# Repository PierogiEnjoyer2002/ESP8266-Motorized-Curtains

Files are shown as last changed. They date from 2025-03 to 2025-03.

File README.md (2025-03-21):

# 🪟 AutoBlinds – ESP8266 Motorized Curtains Controller

## Overview
AutoBlinds is a DIY smart curtains controller built using **ESP8266 (Wemos D1 Mini)** and a stepper motor. This project allows you to control your window curtains via a web interface and physical buttons.

## Features
- **Dual Control Methods**
  - Web interface accessible from any device on your network
  - Physical buttons for manual operation
  
- **Smart Positioning System**
  - Precise position control with memory
  - Configuration mode to set open/close limits
  
- **Reliable & Customizable**
  - Position memory persists through power cycles (EEPROM storage)
  - Simple configuration for adaptation to different window sizes
  - JSON API for integration with home automation systems

## Bill of Materials
Here's a complete list of components needed for this project:

| Quantity | Component | Specifications |
|---|---|---|
| 1 | NEMA17 Stepper Motor | 1.8° step angle, 2.4 kg/cm holding torque |
| 1 | Wemos D1 Mini | ESP8266-based microcontroller |
| 1 | A4988 Stepper Driver | Pololu or compatible |
| 1 | Mini-360 DC-DC Buck Converter | 12V to 5V for Wemos power |
| 1 | 2.1mm Barrel Jack | With terminal block for power input |
| 2 | Push Buttons | Momentary, normally open |
| 1 | Capacitor | 100uF, 25V (for power stabilization) |
| 1 | Power Supply | 12V DC at least 1,5A|
| - | Various Wires | For connections between components |

## How It Works
1. **The system controls a stepper motor** that opens or closes curtains.
2. **Users operate curtains** via web interface or physical buttons.
3. **Position data is saved** to ensure consistent operation over time.

## 3D Printed Components
This project uses several custom 3D printed parts to create a complete curtain control system:

### Electronics Housing
Electronics Housing

A custom-designed enclosure for the electronics that:
- Securely houses the Wemos D1 Mini, A4988 driver, and DC-DC converter
- Features openings for power and button connections

### Curtain String Guide
String Guide

A specially designed bracket that:
- Guides the curtain string through a smooth path
- Reduces friction for smoother operation
- Prevents tangling during operation
- Easily mounts to window frames of various sizes

### NEMA17 Motor Mount
For the motor mount, I used a design by stevetheprinter:
- Original design available on [Thingiverse](https://www.thingiverse.com/stevetheprinter/designs)
- Features secure mounting for NEMA17 stepper motor

*All STL files for the 3D printed components are included in the `/3d_models` directory of this repository.*

## Installation & Setup

### Hardware Assembly
<p float="left">
  Complete Setup
  Controller Box
</p>

### Software Setup
1. Copy code from repository

2. Configure WiFi Settings
Edit the following lines in the code to match your network:
```cpp
const char* ssid = "Your_WiFi_SSID";       
const char* password = "Your_WiFi_Password"; 
```

3. Configure Static IP
Edit the following lines if you want to use a different IP:
```cpp
IPAddress staticIP(192, 168, 0, 101);
IPAddress gateway(192, 168, 0, 1);
IPAddress subnet(255, 255, 255, 0);
```

4. Upload to ESP8266
Upload the code to your Wemos D1 Mini using the Arduino IDE.

## Usage Instructions

### Web Interface
Access the web interface by navigating to the device's IP address (default: 192.168.0.101) in your web browser.

The interface offers:
- Full open/close buttons
- Stop button
- Position slider for precise control
- Current position and status information

### Physical Buttons
- **Normal Mode:**
  - Short press UP button: Fully open blinds
  - Short press DOWN button: Fully close blinds
  - Press both buttons simultaneously for 3 seconds: Enter configuration mode

- **Configuration Mode:**
  - Short press UP button: Move up continuously (stop with any button)
  - Short press DOWN button: Move down continuously (stop with any button)
  - Long press UP button (3+ seconds): Set current position as fully open
  - Long press DOWN button (3+ seconds): Set current position as fully closed
  - Press both buttons simultaneously for 3 seconds: Exit configuration mode and save settings

### API Endpoint
The system provides a JSON API endpoint at `/status` that returns current position, target position, and operational state.

## Project Images
### Complete Setup
Complete Setup

### Controller Box
Controller Box

### Web Interface
Web Interface

## Video Demonstration
Video showing blinds operation

## Challenges and Solutions
- **Motor Torque Requirements:** Selected NEMA17 motor with sufficient torque for smooth operation.
- **Position Memory:** Implemented EEPROM storage to maintain settings through power cycles.
- **User-Friendly Interface:** Created an intuitive web interface for easy control.
- **3D Printed Components:** Designed custom parts to ensure proper mechanical operation and clean installation.

## Future Improvements
- Add MQTT support for smart home integration (Home Assistant, etc.)

## Author
- **[PierogiEnjoyer2002](https://github.com/PierogiEnjoyer2002)**

## License
This project is open-source and available under the GPL License.

## Contact
Have questions or suggestions? Open an issue or reach out via email at [kamil.piotr.wojnarski@gmail.com](kamil.piotr.wojnarski@gmail.com).

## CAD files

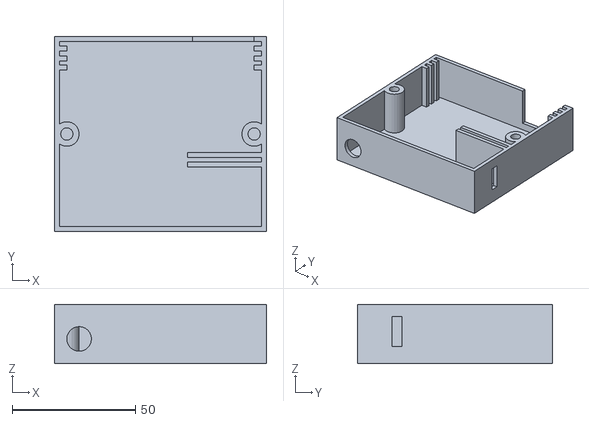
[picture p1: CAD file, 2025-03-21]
3d_models/case.stl
86.0 x 79.0 x 24.0

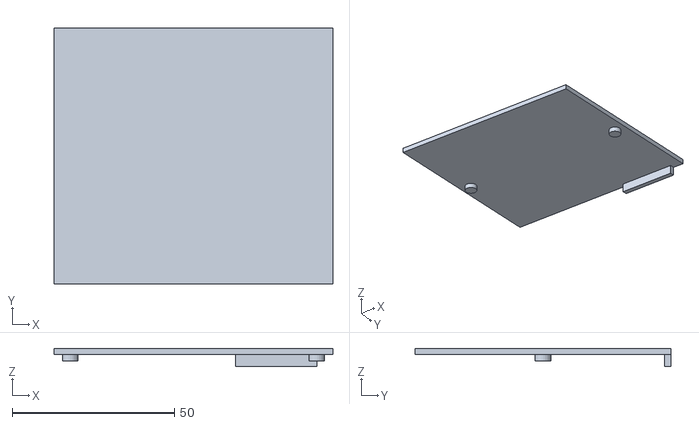
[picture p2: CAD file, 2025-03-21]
3d_models/lid.stl
86.0 x 79.0 x 5.70

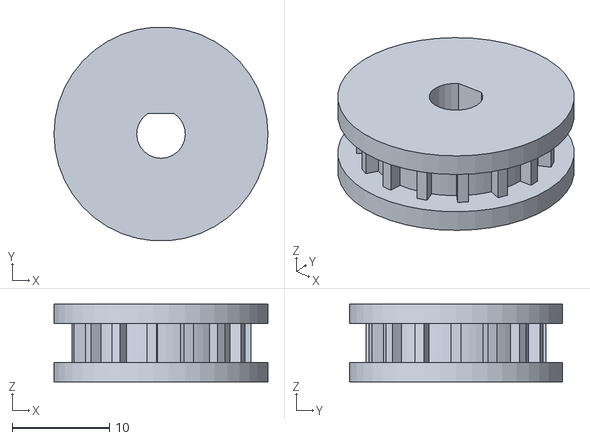
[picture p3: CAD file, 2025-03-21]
3d_models/cog.stl
22.0 x 21.9 x 8.00

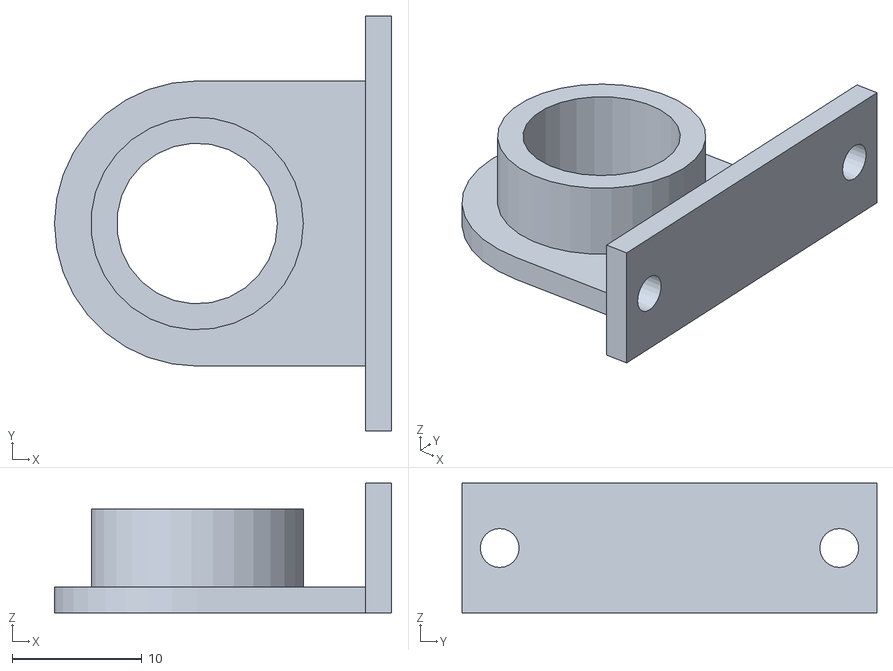
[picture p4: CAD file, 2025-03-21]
3d_models/guide_part_1.stl
26.0 x 32.0 x 10.00

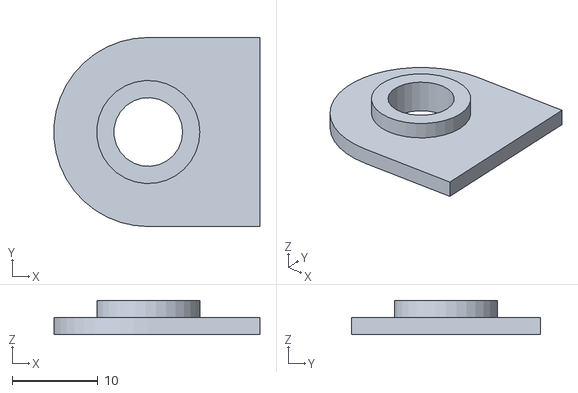
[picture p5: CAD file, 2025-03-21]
3d_models/guide_part_2.stl
24.0 x 22.0 x 4.00

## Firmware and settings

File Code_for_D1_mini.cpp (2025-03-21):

#include <ESP8266WiFi.h>
#include <ESP8266WebServer.h>
#include <ESP8266mDNS.h>
#include <EEPROM.h>

// WiFi Configuration
const char* ssid = "Your_WiFi_SSID";       
const char* password = "Your_WiFi_Password"; 
const char* hostname = "SmartCurtains";          

// Pin definitions
const int stepPin = D8;
const int dirPin = D7;
const int buttonUp = D1;        // Button for opening
const int buttonDown = D2;      // Button for closing
const int ledPin = LED_BUILTIN; // Builti-in LED on wemos D1 mini for configuration mode

// Motor parameters
const int stepsPerRevolution = 200;
const int microstepsPerStep = 16;
const int motorSpeed = 1000;

// Global variables
int currentPosition = 0;
int targetPosition = 0;
int fullOpenPosition = 5000;
int fullClosePosition = 0;
bool isMoving = false;
bool configMode = false;
bool ledState = false;
unsigned long ledBlinkTime = 0;

// Button handling variables
int buttonUpPrevState = HIGH;
int buttonDownPrevState = HIGH;
unsigned long buttonPressStartTime = 0;
bool bothButtonsPressed = false;
bool upPressed_prev = false;
bool downPressed_prev = false;

ESP8266WebServer server(80);
// EEPROM addresses
const int EEPROM_OPEN_ADDR = 0;
const int EEPROM_CLOSE_ADDR = 4;

void setup() {
  Serial.begin(115200);
  // EEPROM initialization
  EEPROM.begin(512);
  // Load saved positions from EEPROM
  loadPositionsFromEEPROM();
  
  // Pin configuration
  pinMode(stepPin, OUTPUT);
  pinMode(dirPin, OUTPUT);
  pinMode(buttonUp, INPUT_PULLUP);
  pinMode(buttonDown, INPUT_PULLUP);
  pinMode(ledPin, OUTPUT);
  digitalWrite(ledPin, HIGH);
  
  // Static IP configuration (change acording to your)
  IPAddress staticIP(192, 168, 0, 101);
  IPAddress gateway(192, 168, 0, 1);
  IPAddress subnet(255, 255, 255, 0);
  IPAddress dns(8, 8, 8, 8);
  WiFi.config(staticIP, gateway, subnet, dns);
  WiFi.mode(WIFI_STA);
  WiFi.hostname(hostname);
  WiFi.begin(ssid, password);
  
  // Wait for connection
  int wifiAttempts = 0;
  while (WiFi.status() != WL_CONNECTED && wifiAttempts < 20) {
    delay(500);
    wifiAttempts++;
  }
  
  if (WiFi.status() == WL_CONNECTED) {
    setupWebServer();
  }
  
  // Signal ready state - flash LED
  for (int i = 0; i < 3; i++) {
    digitalWrite(ledPin, LOW);
    delay(100);
    digitalWrite(ledPin, HIGH);
    delay(100);
  }
}

void loop() {
  if (WiFi.status() == WL_CONNECTED) {
    server.handleClient();
  }
  handleButtons();
  
  // Blink LED in config mode
  if (configMode) {
    if (millis() - ledBlinkTime > 500) {
      ledState = !ledState;
      digitalWrite(ledPin, ledState ? LOW : HIGH);
      ledBlinkTime = millis();
    }
  }
  if (isMoving) {
    moveMotor();
  }
}

// Load saved positions from EEPROM
void loadPositionsFromEEPROM() {
  int savedOpenPosition = 0;
  int savedClosePosition = 0;
  
  EEPROM.get(EEPROM_OPEN_ADDR, savedOpenPosition);
  EEPROM.get(EEPROM_CLOSE_ADDR, savedClosePosition);
  
  if (savedOpenPosition > 0 && savedOpenPosition < 100000) {
    fullOpenPosition = savedOpenPosition;
  }
  
  if (savedClosePosition >= 0 && savedClosePosition < 100000) {
    fullClosePosition = savedClosePosition;
  }
  
  // Make sure open position is greater than closed position
  if (fullOpenPosition <= fullClosePosition) {
    // Default values in case if something is wrong
    fullOpenPosition = 5000;
    fullClosePosition = 0;
  }
  
  // Set default position to closed
  currentPosition = fullClosePosition;
  targetPosition = fullClosePosition;
}

// Save positions to EEPROM
void savePositionsToEEPROM() {
  EEPROM.put(EEPROM_OPEN_ADDR, fullOpenPosition);
  EEPROM.put(EEPROM_CLOSE_ADDR, fullClosePosition);
  EEPROM.commit();
}

// Button handling function
void handleButtons() {
  // Read button states
  bool upPressed = digitalRead(buttonUp) == LOW;
  bool downPressed = digitalRead(buttonDown) == LOW;
  
  // Handle simultaneous button press (mode switching)
  if (upPressed && downPressed) {
    if (isMoving) {
      isMoving = false;
      targetPosition = currentPosition;
    }
    
    if (!bothButtonsPressed) {
      // Start countdown
      buttonPressStartTime = millis();
      bothButtonsPressed = true;
    } else {
      // Check if 3 seconds have passed
      unsigned long elapsedTime = millis() - buttonPressStartTime;
      
      if (elapsedTime >= 3000) {
        // Change mode
        configMode = !configMode;
        
        // Set LED accordingly
        digitalWrite(ledPin, configMode ? LOW : HIGH);
        
        // When exiting config mode, save settings to EEPROM
        if (!configMode) {
          savePositionsToEEPROM();
        }
        bothButtonsPressed = false;
        delay(10);
        while (digitalRead(buttonUp) == LOW || digitalRead(buttonDown) == LOW) {
          delay(10);
        }
        
        // Additional delay to avoid bounce
        delay(100);
        return;
      }
    }
    
    upPressed_prev = upPressed;
    downPressed_prev = downPressed;
    return;
  } else {
    if (bothButtonsPressed) {
      bothButtonsPressed = false;
    }
    
    // CONFIG MODE button handling
    if (configMode) {
      // Static variables for config mode
      static unsigned long upPressStartTime = 0;
      static unsigned long downPressStartTime = 0;
      static bool upWaitingForAction = false;
      static bool downWaitingForAction = false;
      
      if (upPressed && !upPressed_prev) {
        upPressStartTime = millis();
        upWaitingForAction = true;
        
        if (isMoving) {
          isMoving = false;
          targetPosition = currentPosition;
          upWaitingForAction = false;
        }
      }
      
      // UP button - detect long press
      if (upPressed && upWaitingForAction) {
        unsigned long pressDuration = millis() - upPressStartTime;
        
        if (pressDuration >= 3000) {
          fullOpenPosition = currentPosition;
          
          // Flash LED for confirmation
          for (int i = 0; i < 3; i++) {
            digitalWrite(ledPin, HIGH);
            delay(100);
            digitalWrite(ledPin, LOW);
            delay(100);
          }
          upWaitingForAction = false;
        }
      }
      
      // UP button - detect release (short press)
      if (!upPressed && upPressed_prev && upWaitingForAction) {
        unsigned long pressDuration = millis() - upPressStartTime;
        
        if (pressDuration < 1000) {
          targetPosition = currentPosition + 10000;
          isMoving = true;
        }
        upWaitingForAction = false;
      }
      
      // DOWN button - detect press
      if (downPressed && !downPressed_prev) {
        downPressStartTime = millis();
        downWaitingForAction = true;
        
        if (isMoving) {
          isMoving = false;
          targetPosition = currentPosition;
          downWaitingForAction = false;
        }
      }
      
      // DOWN button - detect long press
      if (downPressed && downWaitingForAction) {
        unsigned long pressDuration = millis() - downPressStartTime;
        
        if (pressDuration >= 3000) {
          fullClosePosition = currentPosition;
          
          for (int i = 0; i < 3; i++) {
            digitalWrite(ledPin, HIGH);
            delay(100);
            digitalWrite(ledPin, LOW);
            delay(100);
          }
          
          downWaitingForAction = false;
        }
      }
      
      // DOWN button - detect release (short press)
      if (!downPressed && downPressed_prev && downWaitingForAction) {
        unsigned long pressDuration = millis() - downPressStartTime;
        
        if (pressDuration < 1000) {
          targetPosition = currentPosition - 10000; // Large negative value, will stop with button
          isMoving = true;
        }
        downWaitingForAction = false;
      }
    } 
    // NORMAL MODE button handling
    else {
      // Static variables for normal mode
      static unsigned long upNormalPressStartTime = 0;
      static unsigned long downNormalPressStartTime = 0;
      static bool upNormalWaitingForAction = false;
      static bool downNormalWaitingForAction = false;
      
      // UP button - detect press
      if (upPressed && !upPressed_prev) {
        upNormalPressStartTime = millis();
        upNormalWaitingForAction = true;
        
        if (isMoving) {
          isMoving = false;
          targetPosition = currentPosition;
          upNormalWaitingForAction = false;
        }
      }
      
      // UP button - detect release (short press)
      if (!upPressed && upPressed_prev && upNormalWaitingForAction) {
        unsigned long pressDuration = millis() - upNormalPressStartTime;
        
        if (pressDuration < 1000) {
          targetPosition = fullOpenPosition;
          isMoving = true;
        }
        
        upNormalWaitingForAction = false;
      }
      
      if (downPressed && !downPressed_prev) {
        downNormalPressStartTime = millis();
        downNormalWaitingForAction = true;
        
        if (isMoving) {
          isMoving = false;
          targetPosition = currentPosition;
          downNormalWaitingForAction = false;
        }
      }
      
      // DOWN button - detect release (short press)
      if (!downPressed && downPressed_prev && downNormalWaitingForAction) {
        unsigned long pressDuration = millis() - downNormalPressStartTime;
        
        if (pressDuration < 1000) {
          targetPosition = fullClosePosition;
          isMoving = true;
        }
        downNormalWaitingForAction = false;
      }
    }
  }
  
  upPressed_prev = upPressed;
  downPressed_prev = downPressed;
}

// Configure HTTP server
void setupWebServer() {
  // Home page - control interface
  server.on("/", HTTP_GET, []() {
    String html = "<!DOCTYPE html><html><head>";
    html += "<meta name='viewport' content='width=device-width, initial-scale=1'>";
    html += "<title>Blind Controller</title>";
    html += "<style>";
    html += "body { font-family: Arial, sans-serif; text-align: center; margin: 0; padding: 20px; }";
    html += "h1 { color: #0066CC; }";
    html += ".btn { background-color: #0066CC; color: white; border: none; padding: 15px 25px; ";
    html += "margin: 10px; font-size: 16px; border-radius: 5px; cursor: pointer; }";
    html += ".btn:hover { background-color: #0055AA; }";
    html += ".slider { width: 80%; margin: 30px auto; }";
    html += ".info { margin: 20px; padding: 10px; background-color: #f0f0f0; border-radius: 5px; }";
    html += "</style>";
    html += "</head><body>";
    html += "<h1>Blind Controller</h1>";
    
    // Buttons for full open/close
    html += "<div>";
    html += "<button class='btn' onclick='window.location.href=\"/up\"'>Fully Open</button>";
    html += "<button class='btn' onclick='window.location.href=\"/down\"'>Fully Close</button>";
    html += "<button class='btn' onclick='window.location.href=\"/stop\"'>Stop</button>";
    html += "</div>";
    
    // Slider for position setting
    int minPos = fullClosePosition;
    int maxPos = fullOpenPosition;
    html += "<div class='slider'>";
    html += "<input type='range' min='" + String(minPos) + "' max='" + String(maxPos) + "' value='" + String(currentPosition) + "' id='posSlider' ";
    html += "oninput='updatePosition(this.value)' onchange='setPosition(this.value)'>";
    html += "</div>";
    
    // Current position info
    html += "<div class='info'>";
    html += "Current position: <span id='posValue'>" + String(currentPosition) + "</span> / " + String(maxPos);
    html += "<br>Range: " + String(minPos) + " - " + String(maxPos);
    html += "<br>Status: " + String(isMoving ? "Moving" : "Stopped");
    html += "<br>Mode: " + String(configMode ? "Configuration" : "Normal");
    html += "</div>";
    
    // JavaScript scripts
    html += "<script>";
    html += "function updatePosition(pos) { document.getElementById('posValue').innerHTML = pos; }";
    html += "function setPosition(pos) { window.location.href = '/set?pos=' + pos; }";
    html += "</script>";
    html += "</body></html>";
    
    server.send(200, "text/html", html);
  });
  
  // Endpoint for full open
  server.on("/up", HTTP_GET, []() {
    targetPosition = fullOpenPosition;
    isMoving = true;
    server.sendHeader("Location", "/");
    server.send(302, "text/plain", "");
  });
  
  // Endpoint for full close
  server.on("/down", HTTP_GET, []() {
    targetPosition = fullClosePosition;
    isMoving = true;
    server.sendHeader("Location", "/");
    server.send(302, "text/plain", "");
  });
  
  // Endpoint for stop
  server.on("/stop", HTTP_GET, []() {
    isMoving = false;
    targetPosition = currentPosition;
    server.sendHeader("Location", "/");
    server.send(302, "text/plain", "");
  });
  
  // Endpoint for setting specific position
  server.on("/set", HTTP_GET, []() {
    if (server.hasArg("pos")) {
      targetPosition = server.arg("pos").toInt();
      // Limit to range fullClosePosition-fullOpenPosition
      targetPosition = constrain(targetPosition, fullClosePosition, fullOpenPosition);
      isMoving = true;
    }
    server.sendHeader("Location", "/");
    server.send(302, "text/plain", "");
  });
  
  // API endpoint for getting status as JSON
  server.on("/status", HTTP_GET, []() {
    String json = "{";
    json += "\"position\":" + String(currentPosition) + ",";
    json += "\"target\":" + String(targetPosition) + ",";
    json += "\"open_position\":" + String(fullOpenPosition) + ",";
    json += "\"close_position\":" + String(fullClosePosition) + ",";
    json += "\"is_moving\":" + String(isMoving ? "true" : "false") + ",";
    json += "\"config_mode\":" + String(configMode ? "true" : "false");
    json += "}";
    server.send(200, "application/json", json);
  });
  
  // Handle unknown paths
  server.onNotFound([]() {
    server.send(404, "text/plain", "Page not found");
  });
  server.begin();
}

// Motor movement handling
void moveMotor() {
  // Determine direction of movement
  if (currentPosition < targetPosition) {
    if (!configMode && currentPosition >= fullOpenPosition) {
      isMoving = false;
      currentPosition = fullOpenPosition;
      targetPosition = fullOpenPosition;
      return;
    }
    
    // Upward movement
    digitalWrite(dirPin, HIGH);
    digitalWrite(stepPin, HIGH);
    delayMicroseconds(motorSpeed);
    digitalWrite(stepPin, LOW);
    delayMicroseconds(motorSpeed);
    
    currentPosition++;
  } 
  else if (currentPosition > targetPosition) {
    if (!configMode && currentPosition <= fullClosePosition) {
      isMoving = false;
      currentPosition = fullClosePosition;
      targetPosition = fullClosePosition;
      return;
    }
    
    // Downward movement
    digitalWrite(dirPin, LOW);
    digitalWrite(stepPin, HIGH);
    delayMicroseconds(motorSpeed);
    digitalWrite(stepPin, LOW);
    delayMicroseconds(motorSpeed);
    
    currentPosition--;
  } 
  else {
    isMoving = false;
  }
}
